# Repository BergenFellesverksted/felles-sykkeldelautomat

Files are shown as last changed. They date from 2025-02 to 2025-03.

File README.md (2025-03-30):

# FELLES Sykkeldelautomat

This document describes the setup, hardware, software, and integration of the FELLES Sykkeldelautomat - a bike part vending machine built from an IKEA Kallax shelf with electronically controlled locker doors.

---

## Table of Contents

- [Overview](#overview)
- [System Highlights](#system-highlights)
- [Hardware Overview](#hardware-overview)
- [Wiring and Pinouts](#wiring-and-pinouts)
  - [Raspberry Pi ↔ I²C LCD](#raspberry-pi--i²c-lcd)
  - [Raspberry Pi ↔ 4×4 Matrix Keypad](#raspberry-pi--4x4-matrix-keypad)
  - [Arduino Mega 2560 ↔ Relay Boards](#arduino-mega-2560--relay-boards)
- [Raspberry Pi Software](#raspberry-pi-software)
  - [order_service.py](#orderservicepy)
  - [online_unlocks.py](#online_unlockspy)
  - [constantsTemplate.py](#constantstemplatepy)
  - [Test Scripts](#test-scripts)
  - [Systemd Services](#systemd-services)
- [Website API and WooCommerce Integration](#website-api-and-woocommerce-integration)
  - [WooCommerce Hooks](#woocommerce-hooks)
  - [API Endpoints](#api-endpoints)
  - [Admin Web Interface](#admin-web-interface)
- [Setup Guide](#setup-guide)
  - [1. Hardware Assembly and Wiring](#1-hardware-assembly-and-wiring)
  - [2. Raspberry Pi Software Setup](#2-raspberry-pi-software-setup)
  - [3. Arduino Firmware Setup](#3-arduino-firmware-setup)
  - [4. WooCommerce and Server Setup](#4-woocommerce-and-server-setup)
  - [5. Maintenance and Use](#5-maintenance-and-use)

---

## Overview

This repository contains the files and instructions needed to build your own **Sykkeldelautomat** (bike part vending machine) or to maintain the one at FELLES SykkelLab.

The **FELLES Sykkeldelautomat** integrates a Raspberry Pi, an Arduino Mega 2560, and two 16-channel relay boards to control 12V electronic cabinet locks mounted on a modified IKEA Kallax shelf. The system interacts with a WooCommerce online store to manage item orders and pickups using unique pickup and return codes.

Items are ordered through the [BergenFellesverksted.no](https://bergenfellesverksted.no) WooCommerce online store. When an item belongs to the Sykkeldelautomat category, a pickup code is automatically sent to the buyer. Additionally, each item is assigned a door using a WooCommerce `attribute` formatted as `Door = NN`.

---

## System Highlights

- **Raspberry Pi 3B+:**
  - Runs software to manage user inputs via a 4×4 matrix keypad.
  - Outputs feedback on an I²C LCD display.
  - Communicates with an Arduino over USB and with a remote API.

- **Arduino Mega 2560:**
  - Controls relays that power the 12V locks.
  - Listens for serial commands from the Raspberry Pi.

- **WooCommerce Integration:**
  - A set of custom functions assigns unique pickup/return/opening codes to orders and bookings.
  - API endpoints allow the Raspberry Pi to fetch new orders and report pickups.

- **Remote Administration:**
  - A web interface allows admins to send unlock commands to individual doors.

---

## Hardware Overview

- **Modified IKEA Kallax Shelf:**  
  Used as the cabinet with custom locker-style doors.

- **12V Electronic Cabinet Locks:**  
  Each door is secured by a lock activated when 12V power is applied.

- **Two 16-Channel Relay Boards:**  
  - **Relay Board 1:** Controls doors 1–16 using Arduino’s odd-numbered pins.
  - **Relay Board 2:** Controls doors 17–20 (and extra channels for future expansion) using Arduino’s even-numbered pins.

- **Arduino Mega 2560:**  
  Manages digital outputs to the relay boards and communicates with the Raspberry Pi via USB.

- **Raspberry Pi 3B+:**  
  Handles user input (keypad), output (LCD), and network communication with the web API.

- **Power Supplies:**  
  Separate 5V (for Pi and Arduino) and 12V (for the locks) power sources. In our case there is a 12V - 5V stepdown converter powering the Pi and Arduino.

Below is the system schematic:

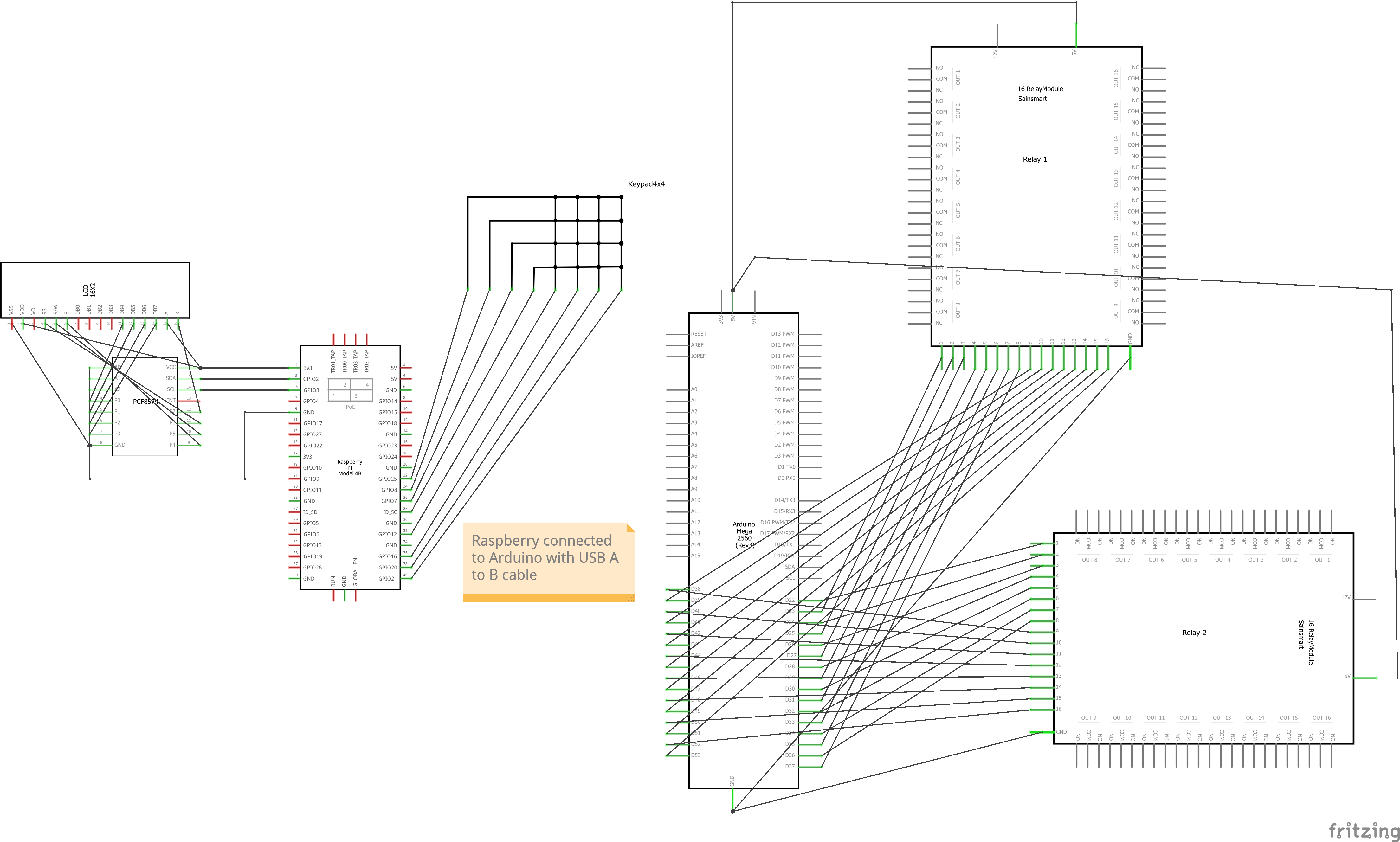
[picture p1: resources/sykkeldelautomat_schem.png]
System Schematic


---

## Wiring and Pinouts

### Raspberry Pi ↔ I²C LCD

| Raspberry Pi Pin | LCD I²C Backpack Pin |
| --- | --- |
| 3.3V (Pin 1) | VCC |
| GND (Pin 6) | GND |
| GPIO 2 (Pin 3, SDA) | SDA |
| GPIO 3 (Pin 5, SCL) | SCL |

*Ensure I²C is enabled on the Raspberry Pi (via `raspi-config`). The typical I²C address is `0x27`.*

### Raspberry Pi ↔ 4×4 Matrix Keypad

| Raspberry Pi GPIO Pin | Keypad Pin (Function) |
| --- | --- |
| GPIO 21 | Pin 1 (Column 4) |
| GPIO 20 | Pin 2 (Column 3) |
| GPIO 16 | Pin 3 (Column 2) |
| GPIO 12 | Pin 4 (Column 1) |
| GPIO 1 | Pin 5 (Row 4) |
| GPIO 7 | Pin 6 (Row 3) |
| GPIO 8 | Pin 7 (Row 2) |
| GPIO 25 | Pin 8 (Row 1) |

*(Pin 1 is on the left when viewed from the front)*

### Arduino Mega 2560 ↔ Relay Boards

#### Relay Board 1 – Doors 1–16

| Arduino Pin | Relay Channel (Door) |
| --- | --- |
| 23 | 1 (Door 1) |
| 25 | 2 (Door 2) |
| 27 | 3 (Door 3) |
| 29 | 4 (Door 4) |
| 31 | 5 (Door 5) |
| 33 | 6 (Door 6) |
| 35 | 7 (Door 7) |
| 37 | 8 (Door 8) |
| 39 | 9 (Door 9) |
| 41 | 10 (Door 10) |
| 43 | 11 (Door 11) |
| 45 | 12 (Door 12) |
| 47 | 13 (Door 13) |
| 49 | 14 (Door 14) |
| 51 | 15 (Door 15) |
| 53 | 16 (Door 16) |

#### Relay Board 2 – Doors 17–20

| Arduino Pin | Relay Channel (Door) |
| --- | --- |
| 22 | 1 (Door 17) |
| 24 | 2 (Door 18) |
| 26 | 3 (Door 19) |
| 28 | 4 (Door 20) |
| 30 | 5 |
| 32 | 6 |
| 34 | 7 |
| 36 | 8 |
| 38 | 9 |
| 40 | 10 |
| 42 | 11 |
| 44 | 12 |
| 46 | 13 |
| 48 | 14 |
| 50 | 15 |
| 52 | 16 |

*Wiring Note:* Each relay channel's normally-open (NO) contact is wired in series with a 12V lock. We break the positive terminal of the locks power through the relay. When activated, the relay closes the circuit, supplying power to unlock the door.

Refer to the image below for a visual overview of the relay boards:

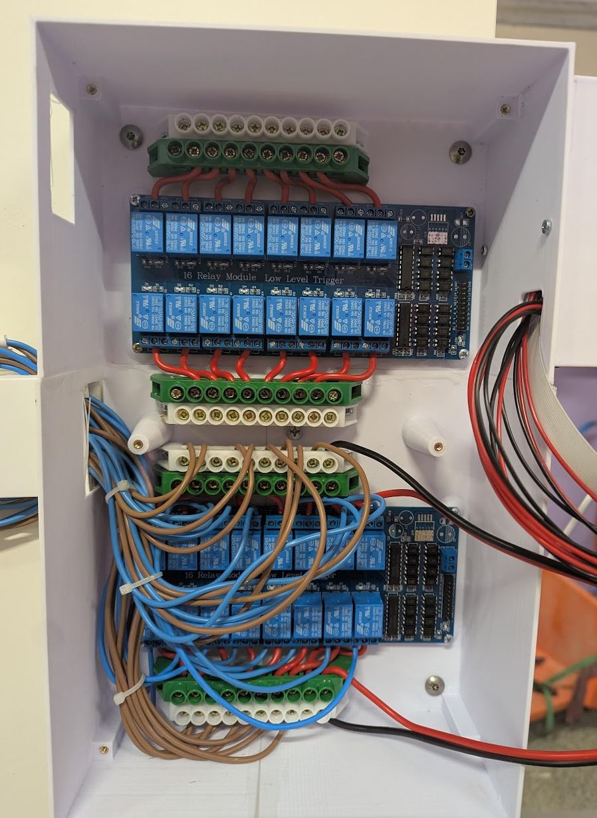
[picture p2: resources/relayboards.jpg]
Relay Boards


And here’s an image of the finished installation:

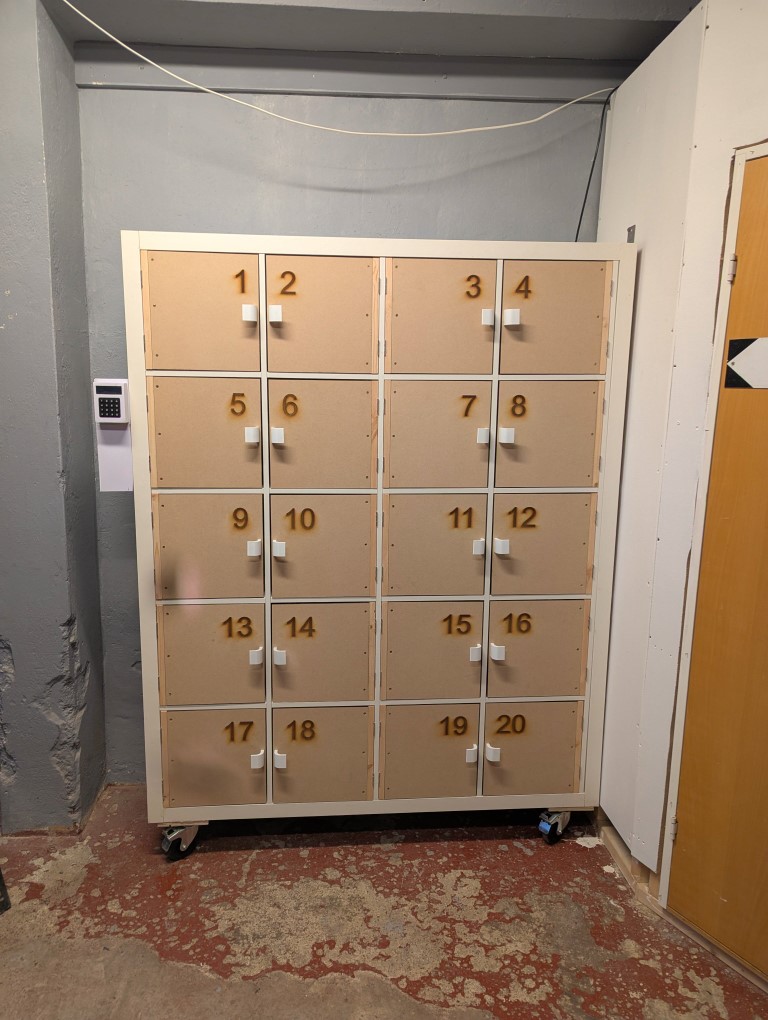
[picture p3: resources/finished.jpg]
Finished Installation


---

## Raspberry Pi Software

All software used on the Raspberry Pi is located in the `raspberrypi/` directory.

### order_service.py

- **Purpose:**  
  - Monitors keypad input.
  - Checks pickup codes against a local SQLite database.
  - Displays user feedback on LCD.
  - Sends serial commands to the Arduino (e.g., `OPEN:<door>:<wait>:<duration>`) to unlock doors.
- **Key Features:**  
  - **Initialization:** Sets up the I²C LCD and GPIO for the keypad.
  - **Database:** Uses SQLite to store order details (IDs, codes, door numbers).
  - **Background Threads:**  
    - *Orders Sync Loop:* Fetches new orders every 60 seconds.
    - *Offline Sync Loop:* Tries to syncs actions done without internet connectivity with the server every 5 minutes.
  - **Serial Communication:** Uses `/dev/ttyUSB0` or `/dev/ttyACM0` at 9600 baud.

### online_unlocks.py

- **Purpose:**  
  - Polls the API endpoint `get_door_requests.php` to retrieve remote unlock requests.
  - Sends commands to the Arduino to open the requested door.
  - Acknowledges the command execution via `mark_request_executed.php`.

### constantsTemplate.py

A configuration file template. Copy it to `constants.py` and modify the following:
- `API_URL` – Base URL of the API.
- `API_KEY` – Secret key for API authentication.
- `DB_FILE` – Path to the local SQLite database.
- `SERIAL_PORT` – Serial port (e.g., `/dev/ttyUSB0` or `/dev/ttyACM0`).
- `OPEN_ALL_CODE` – Master code for opening all doors.
- `ALL_DOORS` – List of all door numbers (default `[1, 2, …, 20]`).

### Test Scripts

Located in the `raspberrypi/test scripts/` directory:
- **test_keypad.py:** Validates keypad wiring and input.
- **test_lcd.py:** Checks LCD display functionality.
- **test_relay.py:** Tests relay activation via the Arduino.
- **test_camera.py:** (Optional) Tests camera and QR code functionality.

### Systemd Services

Two service files are provided for auto-start:
- **order_service.service:** Runs `order_service.py` on boot.
- **online_unlocks.service:** Runs `online_unlocks.py` on boot.

*Example commands to install and start the services:*

```bash
sudo cp /home/pi/felles-sykkeldelautomat/raspberrypi/online_unlocks.service /etc/systemd/system/
sudo cp /home/pi/felles-sykkeldelautomat/raspberrypi/order_service.service /etc/systemd/system/
sudo systemctl daemon-reload
sudo systemctl enable order_service.service
sudo systemctl enable online_unlocks.service
sudo systemctl start order_service.service
sudo systemctl start online_unlocks.service
````

# Website API and WooCommerce Integration

## WooCommerce Hooks `functions.php`

All software used on the website is located in the `website-api/` directory.

### Purpose:
- **Generate unique 4-character pickup and return codes:**  
  Using characters A–D and digits 0–9.
- **Assign codes to orders when payment completes:**  
  (via `woocommerce_payment_complete`).
- **For Bookly bookings:**  
  Assign opening codes based on matching product attributes.

### Door Attribute:
Each product in the vending machine must have a custom attribute `Door` (e.g., `Door = 7`).

## API Endpoints

### orders.php
Outputs JSON data for recent orders. The Raspberry Pi fetches this to update its local SQLite database.

### update_order_pickup.php
Updates an order with a pickup (or opening or return) timestamp after the door is opened.

### get_door_requests.php
Returns pending remote admin unlock requests.

### open_door.php
Allows admin-initiated door open commands via the web interface.

### mark_request_executed.php
Confirms a remote unlock request has been executed.

## Admin Web Interface

### Features:
- **Login-protected:**  
  Uses credentials defined in `constants.php`.
- **Dashboard:**  
  Displays door statuses and recent orders.
- **Remote unlock buttons:**  
  Provides buttons to trigger door opens.

### Database Table:
Create a custom table `sykkeldelautomat_onlinerequests` in your WordPress MySQL database:

```sql
CREATE TABLE IF NOT EXISTS `sykkeldelautomat_onlinerequests` (
  `id` INT NOT NULL AUTO_INCREMENT,
  `door_number` INT NOT NULL,
  `command` VARCHAR(50) DEFAULT 'open',
  `timestamp` DATETIME DEFAULT CURRENT_TIMESTAMP,
  `executed` TINYINT(1) DEFAULT 0,
  PRIMARY KEY (`id`)
);
```

# Setup Guide

## 1. Hardware Assembly and Wiring

### Cabinet and Locks
- **Modify Cabinet:** Use an IKEA Kallax shelf as the cabinet.
- **Install Locks:** Mount 12V cabinet locks on each door.
- **Wiring:** Run wires from each lock to the electronics compartment.

### Mount Electronics
- **Relay Boards:** Install two 16-channel relay boards inside the cabinet.
- **Controllers:** Mount the Arduino Mega 2560 and the Raspberry Pi.

### Power Distribution
- **Power Supply:** Set up a 12V DC power supply for the locks.
- **Lock Wiring:** Wire each lock’s negative lead to the relay’s normally-open (NO) contact and connect the common (COM) to the 12V negative.

### Arduino to Relay Wiring
- **Digital Pins:** Connect Arduino digital pins:
  - Pins 23–53 for Relay Board 1.
  - Pins 22, 24, 26, 28 for Relay Board 2.
- **Power Connections:** Connect Arduino 5 V and GND to the relay boards.

### Raspberry Pi Wiring
- **I²C LCD:** Connect the I²C LCD to the Pi.
- **Keypad:** Wire the 4×4 keypad to the Pi’s GPIO according to the provided mapping.
- **USB Connection:** Connect the Arduino to the Pi via USB.

### Grounding
- **Common Ground:** Ensure all components share a common ground.

---

## 2. Raspberry Pi Software Setup

### Prepare the Pi
- **OS Installation:** Install Raspberry Pi OS and enable I²C (via `raspi-config`).

### Install System Packages
```bash
sudo apt-get update && sudo apt-get upgrade
sudo apt-get install python3-pip python3-venv git libzbar0 i2c-tools
```

### Clone the Repository
```bash
git clone https://github.com/your-repo/felles-sykkeldelautomat.git /home/pi/felles-sykkeldelautomat
```
### Set Up Python Environment
```bash
python3 -m venv /home/pi/.venv
source /home/pi/.venv/bin/activate
pip install -r /home/pi/felles-sykkeldelautomat/raspberrypi/requirements.txt
```
### Configure Constants
```bash
cp /home/pi/felles-sykkeldelautomat/raspberrypi/constantsTemplate.py /home/pi/felles-sykkeldelautomat/raspberrypi/constants.py
nano /home/pi/felles-sykkeldelautomat/raspberrypi/constants.py
```
- Edit values such as `API_URL`, `API_KEY`, `OPEN_ALL_CODE`, `SERIAL_PORT`, etc.

### Test Hardware
#### LCD Test:
```bash
python /home/pi/felles-sykkeldelautomat/raspberrypi/test\ scripts/test_lcd.py
```
#### Keypad Test:
```bash
python /home/pi/felles-sykkeldelautomat/raspberrypi/test\ scripts/test_keypad.py
```
#### Relay Test:
```bash
python /home/pi/felles-sykkeldelautomat/raspberrypi/test\ scripts/test_relay.py
```
#### (Optional) Camera/QR Code Test:
```bash
python /home/pi/felles-sykkeldelautomat/raspberrypi/test\ scripts/test_camera.py
```
### Install and Enable Services
- Follow the Raspberry Pi Software section above for setting up services.

## 3. Arduino Firmware Setup

### Install Arduino IDE
- Set up the Arduino IDE and select **Arduino Mega 2560**.

### Flash the Firmware
- Open `sykkeldelautomat.ino` from the `arduinomega/` folder and upload it.

### Test Serial Communication
- Use the Serial Monitor to send commands (e.g., `OPEN:1:0:5000`).

### Connect the Arduino to the Pi
- Ensure the Arduino is connected via USB for serial communication.

---

## 4. WooCommerce and Server Setup

### WooCommerce Product Setup
- **Product Category:** Create a product category for Sykkeldelautomat items (e.g., "Sykkeldelautomat").
- **Custom Attribute:** Assign each product a custom attribute "Door" with the appropriate number.

### Bookly Integration (Optional)
- Set up Bookly services and ensure they correctly map to WooCommerce products.

### WordPress Code Integration
- Add the provided functions from `website-api/functions.php` to your theme’s `functions.php` or as a custom plugin.

### Upload API Files
- Copy all PHP files from `website-api/` to your server (e.g., `yourdomain.com/api/`).

### Configure constants.php
- Update `constants.php` as needed.

### Database Table
- Create the `sykkeldelautomat_onlinerequests` table (refer to the provided SQL snippet).

### Configure WooCommerce Emails (Optional)
- Customize emails to include pickup instructions and codes.

---

## 5. Maintenance and Use

### Restocking
- Update product door attributes when adding new items.

### Monitoring
- Use the admin web interface to monitor door statuses and order pickups.

### Logs
- Check system logs using `journalctl` for troubleshooting.

### WooCommerce Integration
- Verify that order hooks assign codes correctly and that API endpoints are responsive.

---

By following this guide, you'll have a fully functional **Sykkeldelautomat** that integrates physical hardware with a WooCommerce store, enabling automated item pickups and remote door control.

**Enjoy your new automated pickup system!**

# 3D files and custom PCB
3D files (.step) and a custom PCB design is available in the `resources/3d files` and `resources/kicad_pcb` folders.

## Additional Images
Below are additional images showcasing various components of the system:

- **Custom PCB:**  
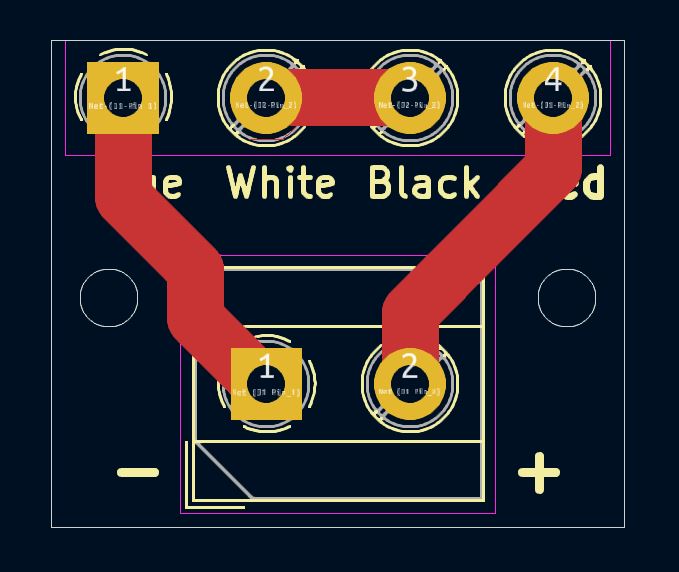
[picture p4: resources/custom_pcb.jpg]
Custom PCB
  

- **LCD Display:**  
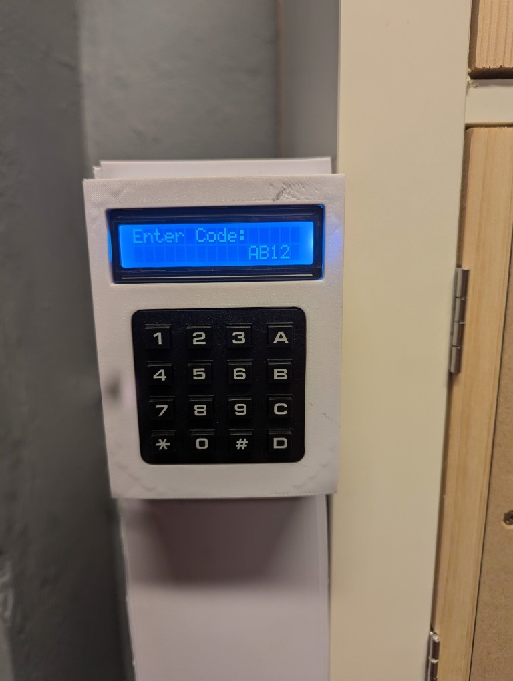
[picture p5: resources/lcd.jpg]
LCD Display
  

- **elektronikk boks.step:**  
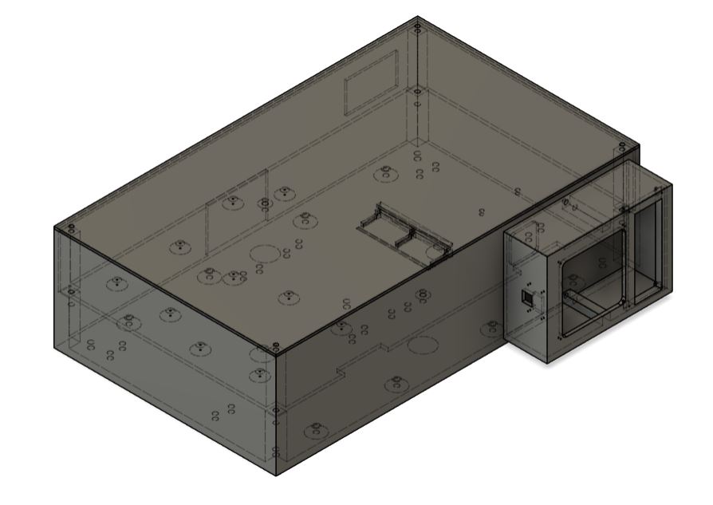
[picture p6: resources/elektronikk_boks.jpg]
Electronics Box
  

- **lock_pcb_box.step:**  
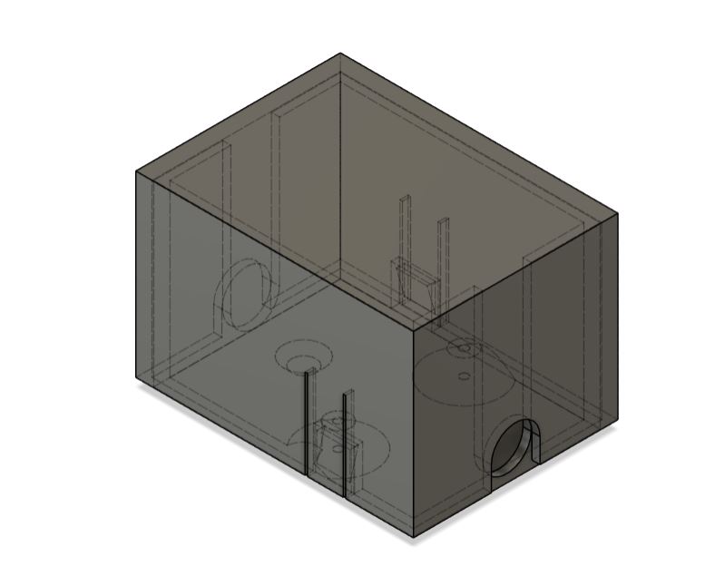
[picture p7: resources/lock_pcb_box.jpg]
Lock PCB Box
  

- **utsalg skapdorer.step:**  
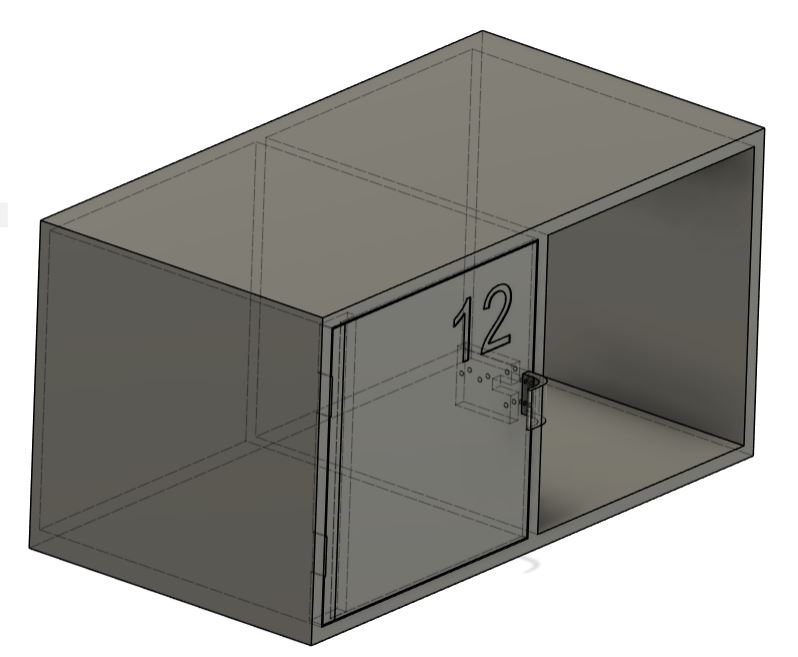
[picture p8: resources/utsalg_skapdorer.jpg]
Vending Machine Doors


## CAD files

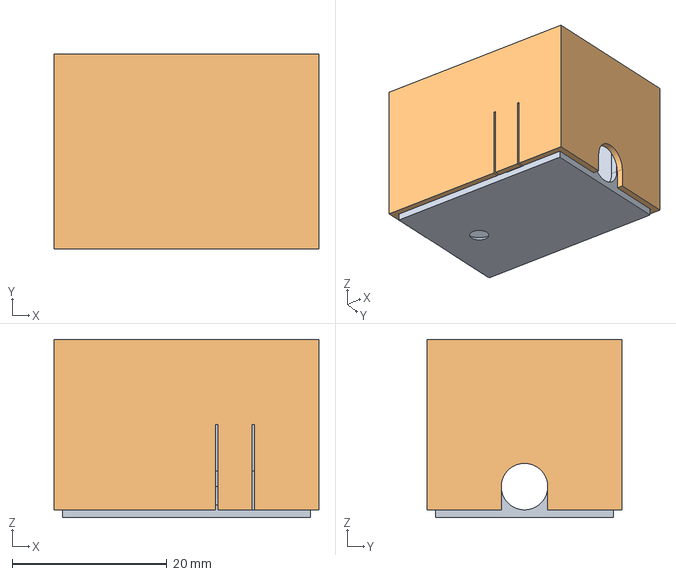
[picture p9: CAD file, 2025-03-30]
resources/3d files/lock_pcb_box.step
34.2 x 25.2 x 23.0 mm

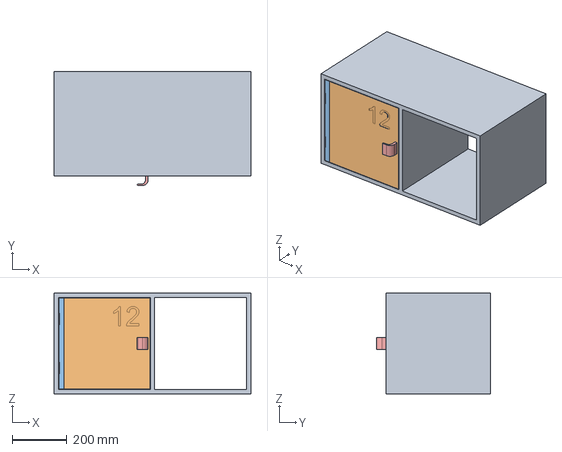
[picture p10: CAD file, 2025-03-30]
resources/3d files/utsalg skapdorer.step
718.0 x 415.0 x 367.0 mm

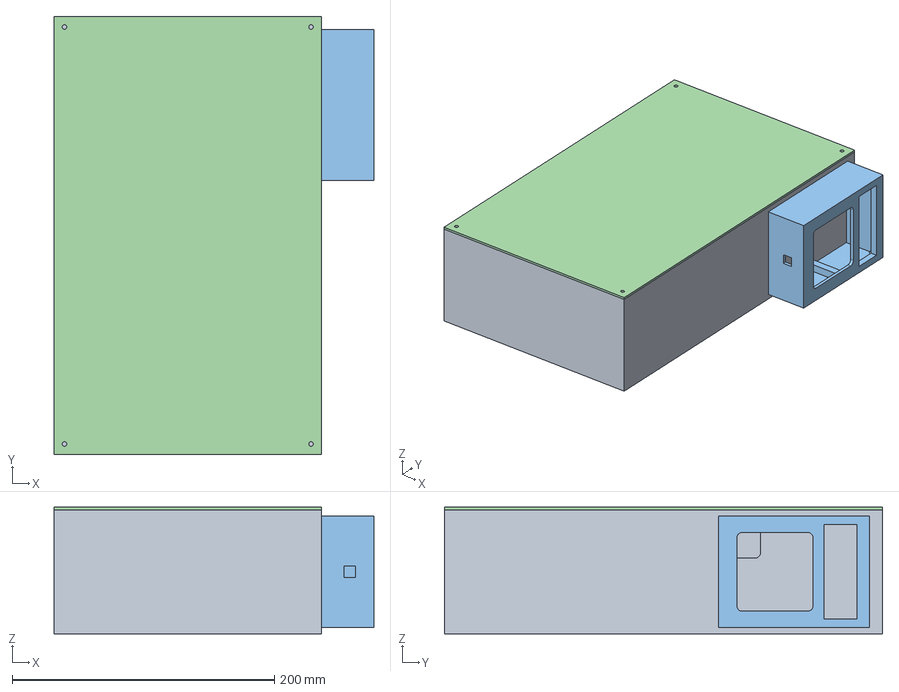
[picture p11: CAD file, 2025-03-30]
resources/3d files/elektronikk boks.step
244.0 x 334.0 x 96.5 mm

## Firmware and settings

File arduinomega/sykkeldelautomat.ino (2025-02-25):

// Flash this code to the Arduino Mega 2560 to control the relay boards
// This code listens for serial commands to open relays for a specified duration

void setup() {
  Serial.begin(9600);

  // Initialize relay pins as output and set them to OFF
  for (int pin = 22; pin <= 53; pin++) {
    pinMode(pin, OUTPUT);
    digitalWrite(pin, HIGH); // HIGH = relay OFF
  }
}

// Store activation timestamps, wait times, and durations for relays
unsigned long relayTimers[32] = {0};  // Activation time storage
unsigned long relayDurations[32] = {0};  // Stores duration for each relay
unsigned long relayWaitTimes[32] = {0};  // Stores wait time before activation
bool relayStates[32] = {false};  // Tracks if relay is on (true) or off (false)

void loop() {
  if (Serial.available() > 0) {
    String command = Serial.readStringUntil('\n');
    
    if (command.startsWith("OPEN:")) {
      String relays = command.substring(5);
      int startIdx = 0;

      while (startIdx < relays.length()) {
        int endIdx = relays.indexOf(',', startIdx);
        if (endIdx == -1) endIdx = relays.length();

        String relayData = relays.substring(startIdx, endIdx);
        int firstColonIdx = relayData.indexOf(':');
        int secondColonIdx = relayData.indexOf(':', firstColonIdx + 1);

        if (firstColonIdx != -1 && secondColonIdx != -1) {
          int relayNum = relayData.substring(0, firstColonIdx).toInt();
          int waitTime = relayData.substring(firstColonIdx + 1, secondColonIdx).toInt();
          int duration = relayData.substring(secondColonIdx + 1).toInt();
          int relayPin;

          if (relayNum >= 1 && relayNum <= 16) {
            relayPin = 22 + (relayNum - 1) * 2; // Map relay 1-16 to 22-52 (even)
          } else if (relayNum >= 17 && relayNum <= 32) {
            relayPin = 23 + (relayNum - 17) * 2; // Map relay 17-32 to 23-53 (odd)
          } else {
            startIdx = endIdx + 1;
            continue; // Invalid relay number, skip
          }

          int relayIndex = relayNum - 1; // Map relayNum to array index
          relayWaitTimes[relayIndex] = millis() + waitTime;  // Store wait time
          relayDurations[relayIndex] = duration;  // Store duration
          relayStates[relayIndex] = false; // Set relay to pending activation
        }

        startIdx = endIdx + 1;
      }

      Serial.println("Relays queued for activation");
    }
  }

  // Check if any relay needs to be turned on
  for (int i = 0; i < 32; i++) {
    if (!relayStates[i] && millis() >= relayWaitTimes[i] && relayDurations[i] > 0) {
      int relayPin;
      if (i < 16) {
        relayPin = 22 + (i * 2);
      } else {
        relayPin = 23 + ((i - 16) * 2);
      }
      digitalWrite(relayPin, LOW); // Turn relay ON
      relayTimers[i] = millis();  // Store activation time
      relayStates[i] = true;
    }
  }

  // Check if any relay needs to be turned off
  for (int i = 0; i < 32; i++) {
    if (relayStates[i] && millis() - relayTimers[i] >= relayDurations[i]) {
      int relayPin;
      if (i < 16) {
        relayPin = 22 + (i * 2);
      } else {
        relayPin = 23 + ((i - 16) * 2);
      }
      digitalWrite(relayPin, HIGH); // Turn relay OFF
      relayStates[i] = false;
      relayTimers[i] = 0;  // Reset the timer
      relayDurations[i] = 0;  // Ensure relay does not turn on again
    }
  }
}

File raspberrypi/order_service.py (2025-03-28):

import time
import requests
import sqlite3
import serial
import threading
import subprocess
import os
import cv2
import numpy as np
from datetime import datetime, timedelta
from pyzbar.pyzbar import decode
from RPi import GPIO
from RPLCD.i2c import CharLCD
from constants import *  # Make sure DB_FILE, API_URL, API_KEY, OPEN_ALL_CODE, ALL_DOORS, etc. are defined here

# ------------------------------------------------------------------------------
# Constants
# ------------------------------------------------------------------------------
DELAY_BETWEEN_GROUPS = 0.5
OFFLINE_SYNC_INTERVAL = 300   # 5 minutes for syncing offline actions
ORDERS_SYNC_INTERVAL = 60     # Sync orders every 60 seconds
LCD_TIMEOUT = 20              # Time before the LCD screen turns off without input
MINUTES_TO_ACCEPT_ORDER_AFTER_PICKUP = 15  # Minutes to allow pickup after pickup time

# Keypad Configuration
KEYPAD = [
    [1, 2, 3, 'A'],
    [4, 5, 6, 'B'],
    [7, 8, 9, 'C'],
    ['*', 0, '#', 'D']
]
ROW_PINS = [12, 16, 20, 21]
COL_PINS = [25, 8, 7, 1]

# ------------------------------------------------------------------------------
# LCD and GPIO Setup
# ------------------------------------------------------------------------------
lcd = CharLCD(i2c_expander='PCF8574', address=0x27, port=1, cols=16, rows=2, dotsize=8)
lcd.backlight_enabled = False

GPIO.setmode(GPIO.BCM)
GPIO.setup(ROW_PINS, GPIO.OUT, initial=GPIO.LOW)
GPIO.setup(COL_PINS, GPIO.IN, pull_up_down=GPIO.PUD_DOWN)

# ------------------------------------------------------------------------------
# Database Initialization
# ------------------------------------------------------------------------------
def initialize_database():
    """Creates the necessary tables if they don't exist."""
    conn = sqlite3.connect(DB_FILE)
    cursor = conn.cursor()

    # Updated orders table: no longer storing return_code/return_time,
    # but storing opening_code, start_time, and end_time.
    cursor.execute("""
        CREATE TABLE IF NOT EXISTS orders (
            order_id INTEGER PRIMARY KEY,
            customer_name TEXT,
            order_date TEXT,
            order_total TEXT,
            pickup_code TEXT,
            pickup_time TEXT,
            opening_code TEXT DEFAULT NULL,
            start_time TEXT DEFAULT NULL,
            end_time TEXT DEFAULT NULL
        );
    """)

    # Table for order items associated with each order
    cursor.execute("""
        CREATE TABLE IF NOT EXISTS order_items (
            order_id INTEGER,
            product_name TEXT,
            door TEXT,
            FOREIGN KEY (order_id) REFERENCES orders(order_id)
        );
    """)

    # Table for storing actions that have not yet been synced with the API
    cursor.execute("""
        CREATE TABLE IF NOT EXISTS offline_actions (
            id INTEGER PRIMARY KEY AUTOINCREMENT,
            order_id INTEGER,
            action TEXT CHECK(action IN ('pickup', 'opening')),
            action_time TEXT DEFAULT (datetime('now')),
            synced INTEGER DEFAULT 0
        );
    """)

    conn.commit()
    conn.close()

# ------------------------------------------------------------------------------
# Orders Sync Functions (runs in its own thread)
# ------------------------------------------------------------------------------
def fetch_orders():
    """Fetch orders from the online API."""
    try:
        response = requests.get(f"{API_URL}orders.php?api_key={API_KEY}")
        response.raise_for_status()
        return response.json()
    except requests.exceptions.RequestException as e:
        print(f"Error fetching orders: {e}")
        return []

def sanitize_value(value):
    """Convert lists to comma-separated strings; otherwise return the value unchanged."""
    if isinstance(value, list):
        return ",".join(str(v) for v in value)
    return value

def update_local_database(orders):
    """Update the local SQLite database with new/updated orders."""
    conn = sqlite3.connect(DB_FILE)
    cursor = conn.cursor()

    for order in orders:
        cursor.execute("""
            INSERT INTO orders (order_id, customer_name, order_date, order_total, pickup_code, pickup_time, opening_code, start_time, end_time)
            VALUES (?, ?, ?, ?, ?, ?, ?, ?, ?)
            ON CONFLICT(order_id) DO UPDATE SET 
                customer_name = excluded.customer_name,
                order_date = excluded.order_date,
                order_total = excluded.order_total,
                pickup_code = excluded.pickup_code,
                pickup_time = excluded.pickup_time,
                opening_code = COALESCE(excluded.opening_code, orders.opening_code),
                start_time = COALESCE(excluded.start_time, orders.start_time),
                end_time = COALESCE(excluded.end_time, orders.end_time);
        """, [
            order["order_id"],
            order["customer_name"],
            order["order_date"],
            order["order_total"],
            order["pickup_code"],
            order["pickup_time"],
            sanitize_value(order.get("opening_code", None)),
            sanitize_value(order.get("start_time", None)),
            sanitize_value(order.get("end_time", None))
        ])

        # Remove existing items to avoid duplicates
        cursor.execute("DELETE FROM order_items WHERE order_id = ?", (order["order_id"],))

        # Insert order items if available
        for item in order.get("items", []):
            cursor.execute("INSERT INTO order_items (order_id, product_name, door) VALUES (?, ?, ?)", (
                order["order_id"], item["product_name"], item["door"]
            ))

    conn.commit()
    conn.close()

def fetch_orders_now():
    print("Fetching orders...")
    orders = fetch_orders()
    if orders:
        update_local_database(orders)
        print(f"Updated {len(orders)} orders.")
    else:
        print("No new orders found.")

def orders_sync_loop():
    """Loop that periodically syncs orders from the API."""
    while True:
        fetch_orders_now()
        time.sleep(ORDERS_SYNC_INTERVAL)

# ------------------------------------------------------------------------------
# Offline Actions Sync (runs in its own thread)
# ------------------------------------------------------------------------------
def sync_offline_actions():
    """Attempts to sync offline actions with the API, including action_time."""
    print("Checking offline pickups")
    conn = sqlite3.connect(DB_FILE)
    cursor = conn.cursor()
    cursor.execute("SELECT id, order_id, action, action_time FROM offline_actions WHERE synced = 0")
    unsynced_actions = cursor.fetchall()

    for action_id, order_id, action, action_time in unsynced_actions:
        if send_order_update(order_id, action, action_time, store_on_fail=False):
            cursor.execute("UPDATE offline_actions SET synced = 1 WHERE id = ?", (action_id,))
    
    conn.commit()
    conn.close()
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

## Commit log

2025-02-10 fixed opening and api call. missing to fix lcd promts
    [order_service.py]
2025-02-11 fixes for order service. camera not running yet
    [order_service.py]
2025-02-12 offline sync, open all doors code, fixing bugs
    [order_service.py, test_camera.py]
2025-02-25 added 15 minute cooldown, fixed bug in offline storing, better lcd text for already returned orders
    [order_service.py, test_relay.py]
2025-02-25 rename arduino file
2025-03-28 fixing of the order_service to deal with the new opening_codes
    [order_service.py]
2025-03-30 more pictures, and 3d models
    [elektronikk boks.step, lock_pcb_box.step, sykkellabLåsesylinderPCB.kicad_pcb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]
2025-08-14 fix for some edge case codes that was not working
